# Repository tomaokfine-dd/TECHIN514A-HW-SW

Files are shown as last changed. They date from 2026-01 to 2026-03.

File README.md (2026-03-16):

# Screen Usage Load Meter

## 1. Project Overview

### What it does

Screen Usage Load Meter is a two-device system that estimates a user's screen usage load based on ambient light and user presence detection.  
A sensing device placed near a screen detects usage patterns, while a desktop display device visualizes the accumulated load using an analog gauge with a stepper motor and LED indicator.

### General Physical Sketch

The system consists of a small sensing module mounted near a computer screen and a desktop gauge display with a needle and LED.

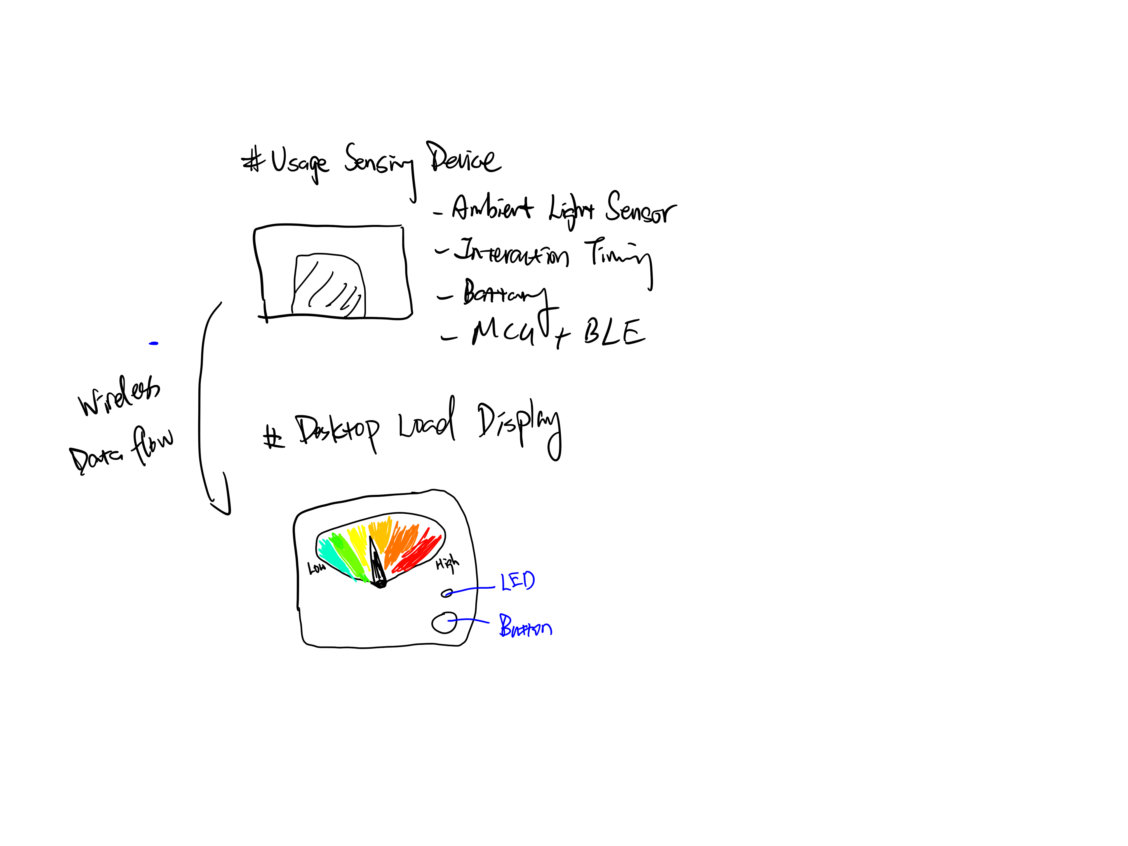
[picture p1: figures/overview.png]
Overview


---

## 2. Sensor Device

The sensor device is a compact, battery-powered module placed near a computer screen.  
It passively detects screen usage behavior without accessing the operating system and wirelessly transmits processed data to the display device via ESP-NOW.

### Sensors and Part Numbers

- **Ambient Light Sensor:** VEML7700 (Adafruit breakout)  
  Used to detect screen-on activity based on lux threshold (< 30 lux = screen off).
- **Time-of-Flight Distance Sensor:** VL53L4CX (Adafruit breakout)  
  Used to detect user presence in front of the screen (> 800mm = no person).

### Processor and Wireless

- **MCU + Wireless:** Seeed Studio XIAO ESP32C3 (ESP32-C3, ESP-NOW over Wi-Fi)

### Power

- 3.7V LiPo battery (1000 mAh)
- Onboard charging via XIAO ESP32C3 built-in battery management

### Sensor Device Sketch

The sensing module is mounted near the display, with the light sensor facing the screen and the distance sensor facing the user.  
The device operates autonomously and does not include user-facing controls.

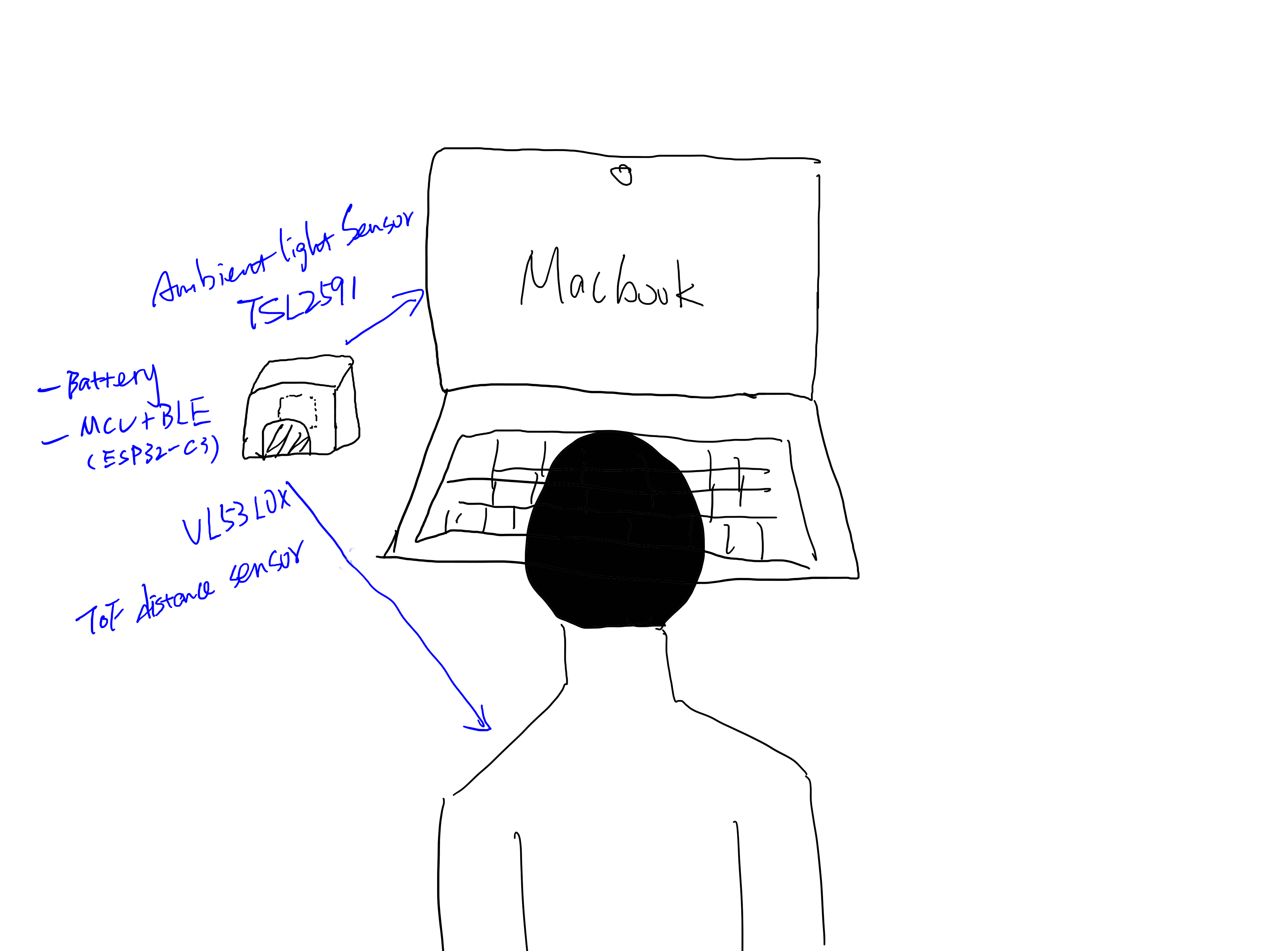
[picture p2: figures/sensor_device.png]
Sensor Device


---

## 3. Display Device

The display device is a desktop physical gauge that visualizes the current screen usage load.  
It integrates a stepper-motor-driven needle and an LED indicator, connected via breadboard prototype.

### Interface Components

- **Stepper Motor:** X27.168 bipolar gauge motor  
  Drives the gauge needle (2° per minute, full range 360°, returns to origin at 180 minutes).
- **LED:** NeoPixel WS2812B (single RGB LED for status indication)  
  Green (0–60 min) → Yellow (60–120 min) → Orange (120–180 min) → Bright Red (180+ min)

### Processor and Wireless

- **MCU + Wireless:** Seeed Studio XIAO ESP32C3  
  Receives data from the sensor device via ESP-NOW and controls motor and LED output.

### Power

- USB 5V (runs alongside computer)

### Display Device Sketch

The display features a gauge with a needle indicating cumulative usage load.  
An LED provides color-coded status, changing color every hour to indicate increasing usage intensity.

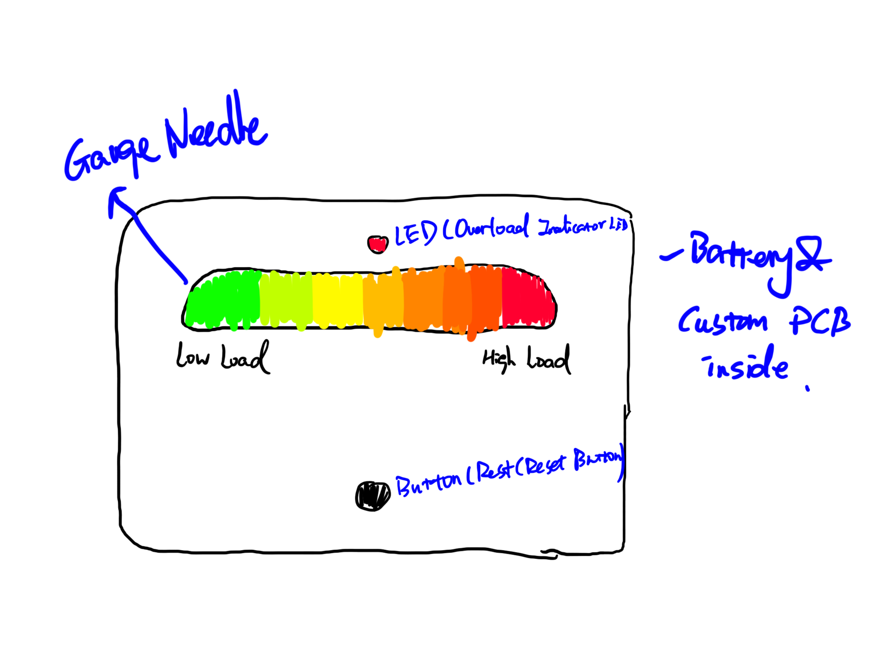
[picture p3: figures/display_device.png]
Display Device


---

## 4. Communication and System Diagram

The sensor device continuously transmits processed usage data to the display device using **ESP-NOW** (peer-to-peer Wi-Fi protocol, no router required). The system converts raw sensor signals into a cumulative screen usage time that controls the gauge needle position and LED color state.

**Data Flow:**

1. Sensor signals (ambient light lux + distance mm)
2. Threshold logic (lux < 30 = screen off; distance > 800mm = no person)
3. Usage timer accumulation (seconds counted when both conditions met)
4. ESP-NOW transmission (minutes sent every second to display device)
5. Output mapping to needle position (2°/min) and LED color stage

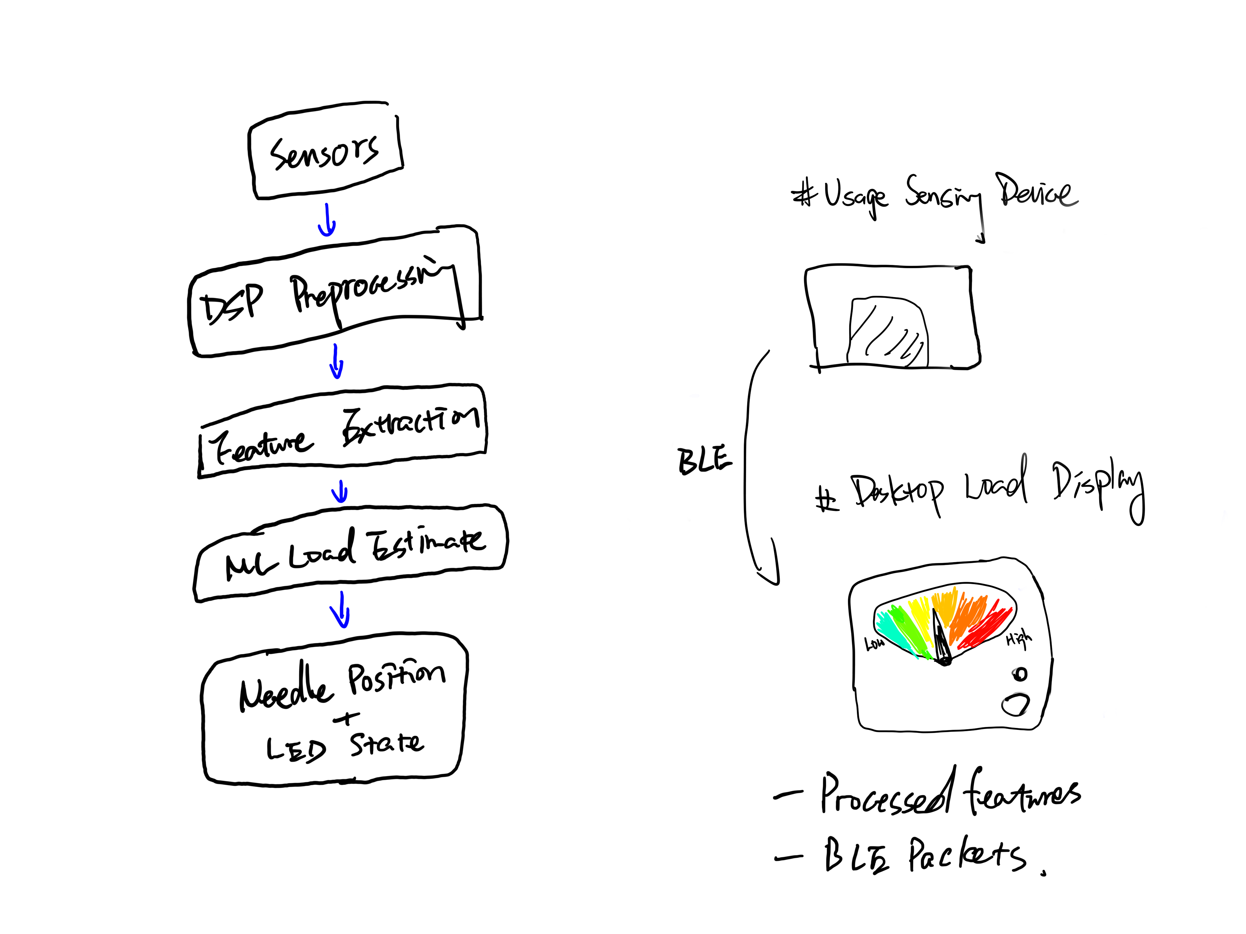
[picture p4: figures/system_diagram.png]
System Diagram


---

## 5. DSP and Signal Processing Approach

- **DSP:**  
  Dual-threshold detection logic combines ambient light and distance signals. Screen-off state is detected when lux drops below 30. User absence is detected when ToF distance exceeds 800mm. Usage time accumulates only when both sensors confirm active use simultaneously.
- **Note:**  
  No ML model is used in the current implementation. Detection is rule-based with fixed thresholds calibrated to typical indoor desktop environments. False positive rate is approximately 5%, primarily caused by ambient light changes such as overhead lighting.

---

## 6. Datasheets

All component datasheets are included in the `/datasheets` folder, including:

- ESP32-C3 (Seeed Studio XIAO ESP32C3)
- VEML7700 Ambient Light Sensor (Vishay / Adafruit breakout)
- VL53L4CX Time-of-Flight Distance Sensor (ST / Adafruit breakout)
- X27.168 Bipolar Gauge Stepper Motor (Switec/Juken)
- WS2812B RGB LED (NeoPixel)
- Custom Sensor Board PCB (KiCad design files)

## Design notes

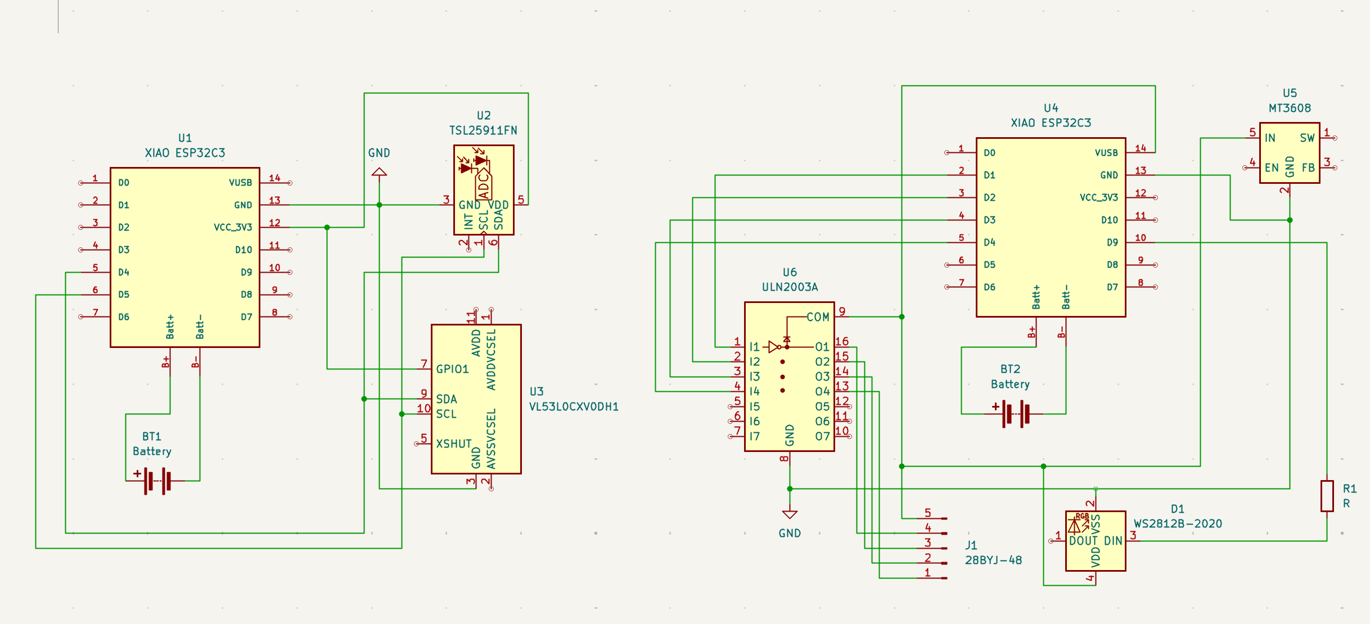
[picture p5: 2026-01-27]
kicad/Untitled/electrical schematics.png

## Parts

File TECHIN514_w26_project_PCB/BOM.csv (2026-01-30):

Reference | Qty | Value | DNP | Exclude from BOM | Exclude from Board | Footprint | Datasheet
C1,C2,C3,C4 | 4 | 1μF |  |  |  | Capacitor_SMD:C_0603_1608Metric_Pad1.08x0.95mm_HandSolder | ~
C5 | 1 | 10μF |  |  |  | Capacitor_SMD:C_0603_1608Metric_Pad1.08x0.95mm_HandSolder | ~
C6 | 1 | ≥10µF |  |  |  | Capacitor_SMD:C_0603_1608Metric_Pad1.08x0.95mm_HandSolder | ~
D1 | 1 | LED |  |  |  | LED_SMD:LED_0603_1608Metric_Pad1.05x0.95mm_HandSolder | ~
J1 | 1 | Conn_01x04 |  |  |  | Connector_PinSocket_1.00mm:PinSocket_1x04_P1.00mm_Vertical | ~
R1,R2,R4 | 3 | 4.7k |  |  |  | Resistor_SMD:R_0603_1608Metric_Pad0.98x0.95mm_HandSolder | ~
R3 | 1 | 330 |  |  |  | Resistor_SMD:R_0603_1608Metric_Pad0.98x0.95mm_HandSolder | ~
U2 | 1 | APDS-9960 |  |  |  | Sensor:Avago_APDS-9960 | https://docs.broadcom.com/doc/AV02-4191EN
U3 | 1 | MIC5376-2.8YC5-TR |  |  |  | APDS-9960:SC-70_C5_MCH | MIC5376-2.8YC5-TR

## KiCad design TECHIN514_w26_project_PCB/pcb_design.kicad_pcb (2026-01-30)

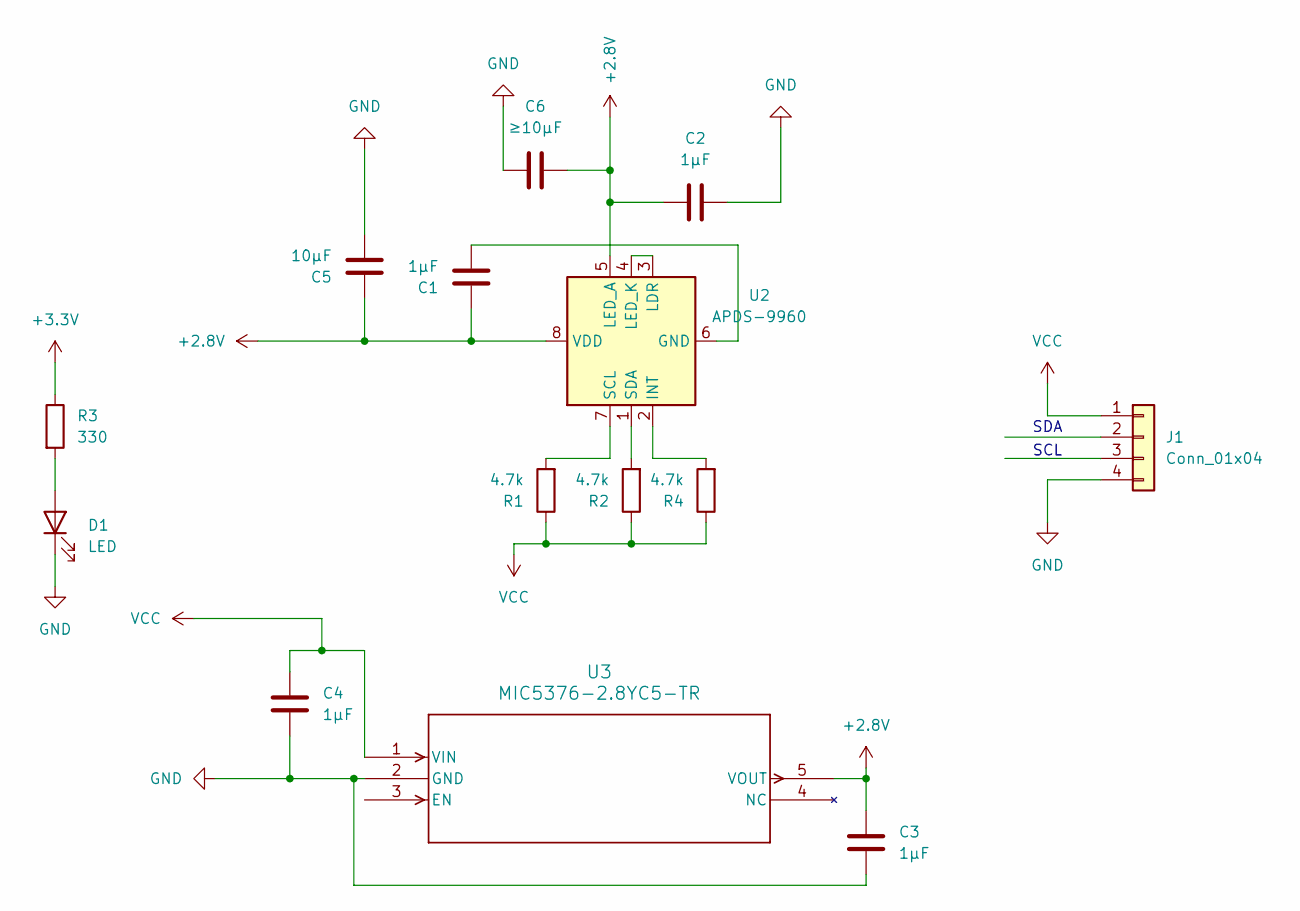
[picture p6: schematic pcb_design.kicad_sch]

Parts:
C1, C2, C3, C4: 1μF; C_0603_1608Metric_Pad1.08x0.95mm_HandSolder
C5: 10μF; C_0603_1608Metric_Pad1.08x0.95mm_HandSolder
C6: ≥10µF; C_0603_1608Metric_Pad1.08x0.95mm_HandSolder
D1: LED; LED_0603_1608Metric_Pad1.05x0.95mm_HandSolder
J1: Conn_01x04; PinSocket_1x04_P1.00mm_Vertical
R1, R2, R4: 4.7k; R_0603_1608Metric_Pad0.98x0.95mm_HandSolder
R3: 330; R_0603_1608Metric_Pad0.98x0.95mm_HandSolder
U2: APDS-9960; Avago_APDS-9960
U3: MIC5376-2.8YC5-TR; SC-70_C5_MCH

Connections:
+2.8V: C1.1, C2.1, C3.1, C5.1, C6.1, U2.5 (LED_A), U2.8 (VDD), U3.5 (VOUT)
+3.3V: R3.1
GND: C2.2, C3.2, C4.2, C5.2, C6.2, D1.1 (K), J1.4, U3.2 (GND)
unnamed: D1.2 (A), R3.2
unnamed: C1.2, U2.6 (GND)
unnamed: R4.2, U2.2 (INT)
unnamed: U2.3 (LDR), U2.4 (LED_K)
unnamed: R1.2, U2.7 (SCL)
unnamed: R2.2, U2.1 (SDA)
VCC: C4.1, J1.1, R1.1, R2.1, R4.1, U3.1 (VIN)

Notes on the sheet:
SDA
SCL

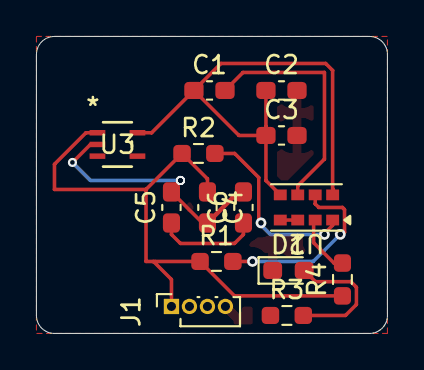
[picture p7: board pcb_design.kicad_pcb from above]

Board: 2 copper layers, 19.5 x 16.5 mm, 14 parts (0 on the bottom side), 9 nets.

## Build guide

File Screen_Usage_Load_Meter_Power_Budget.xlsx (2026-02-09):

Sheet: System Parameters
System Parameters (defined by hardware) |  |  |  | Profiles (usage of each component mode - defined by software and usage)
 | form the datasheets
 |  |  |  | "off" | "sensing" | "interactive"
Processor | 120 |  | 0 | 0.05 | 0.1
Active | 60 | mW | 0 | 20% | 30% | 0%
Idle | 0.28 | mW | 1 | 75% | 60% | 0%
Sleep | 1.00035 | mW |  | 0% | 0% | 0%
LED | 6.6 |  | 0 | 0.03 | 0.05
On | 5.0004 | mW |  | 0% | 0% | 0%
Sensor | 57 |  | 0 | 0.05 | 0.1
On | 0.03 | mW | 0 | 95% | 90% | 0%
Idle | 0.001 | mW | 1 | 0% | 0% | 0%
Off | 1.00045 | mW |  | 0% | 0% | 0%
Display | 0 |  | 0 | 0 | 0
On | 0 | mW | 0 | 0% | 0% | 0%
Off (leakage) | 1.0006 | mW |  | 0% | 0% | 0%
Radio | 0
Data Rate | 350 | bps | 0 | 100% | 90% | 0% |  | Total power in profile (mw) |  |  | Maximum Time
Standby Power | 1200 | mW | 0 | 0% | 10% | 0% |  | "off" | 365.2865 | mW | 0.008523583543 | hours
TX Power | 0 | mW | 1 | 0% | 0% | 0% |  | "sensing" | 459.225 | mW | 0.006780009799 | hours
RX Power | 10.000001 | mW |  | 0% | 0% | 0% |  | "interactive" | 0 | mW | #DIV/0! | hours
 |  |  | 16 | 7 | 1
 |  |  |  | 16 | 7 | 1 | hours/day typical usage | Effective Battery Capacity
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

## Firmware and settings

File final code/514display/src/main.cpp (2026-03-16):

#include <Arduino.h>
#include <WiFi.h>
#include <esp_now.h>
#include <Adafruit_NeoPixel.h>

#define PIN1 4
#define PIN2 6
#define PIN3 8
#define PIN4 9
#define LED_PIN 3
#define NUM_LEDS 1

Adafruit_NeoPixel strip(NUM_LEDS, LED_PIN, NEO_GRB + NEO_KHZ800);

unsigned long receivedMinutes = 0;
unsigned long lastMinutes = 0;
int motorPos = 0;
int lastStage = -1;

typedef struct { unsigned long minutes; } DataPacket;

int motorSteps[4][4] = {
  {1,0,0,1},{1,0,1,0},{0,1,1,0},{0,1,0,1}
};

void setMotor(int step) {
  digitalWrite(PIN1, motorSteps[step][0]);
  digitalWrite(PIN2, motorSteps[step][1]);
  digitalWrite(PIN3, motorSteps[step][2]);
  digitalWrite(PIN4, motorSteps[step][3]);
}

void moveMotor(int steps) {
  if (steps > 0) {
    for (int i = 0; i < steps; i++) {
      motorPos++;
      setMotor(motorPos % 4);
      delay(2);
    }
  } else {
    for (int i = 0; i < abs(steps); i++) {
      motorPos--;
      setMotor(((motorPos % 4) + 4) % 4);
      delay(2);
    }
  }
}

void onReceive(const uint8_t* mac, const uint8_t* data, int len) {
  DataPacket packet;
  memcpy(&packet, data, sizeof(packet));
  receivedMinutes = packet.minutes;
}

int getStage(unsigned long min) {
  if (min < 60) return 0;
  if (min < 120) return 1;
  if (min < 180) return 2;
  return 3;
}

void setLED(int stage) {
  if (stage == 0) {
    strip.setBrightness(20);
    strip.setPixelColor(0, strip.Color(0, 255, 0));
  } else if (stage == 1) {
    strip.setBrightness(20);
    strip.setPixelColor(0, strip.Color(255, 200, 0));
  } else if (stage == 2) {
    strip.setBrightness(20);
    strip.setPixelColor(0, strip.Color(255, 80, 0));
  } else {
    strip.setBrightness(150);
    strip.setPixelColor(0, strip.Color(255, 0, 0));
  }
  strip.show();
}

void setup() {
  Serial.begin(115200);

  pinMode(PIN1, OUTPUT);
  pinMode(PIN2, OUTPUT);
  pinMode(PIN3, OUTPUT);
  pinMode(PIN4, OUTPUT);

  WiFi.mode(WIFI_STA);
  esp_now_init();
  esp_now_register_recv_cb(onReceive);

  strip.begin();
  delay(500);
  setLED(0);

  Serial.println("Started");
}

void loop() {
  if (receivedMinutes != lastMinutes) {
    int diff = (int)(receivedMinutes - lastMinutes);

    if (receivedMinutes >= 180) {
      
      moveMotor(-motorPos);
      Serial.println("Returned to origin");
    } else {
      
      moveMotor(diff * 6);
    }
    lastMinutes = receivedMinutes;
  }

  int stage = getStage(receivedMinutes);
  if (stage != lastStage) {
    setLED(stage);
    lastStage = stage;
  }

  Serial.printf("Total: %lu min | Motor pos: %d\n", receivedMinutes, motorPos);
  delay(1000);
}

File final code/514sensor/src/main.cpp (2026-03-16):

#include <Arduino.h>
#include <Wire.h>
#include <WiFi.h>
#include <esp_now.h>
#include <Adafruit_VEML7700.h>
#include <vl53l4cx_class.h>

Adafruit_VEML7700 veml;
VL53L4CX sensor(&Wire, 2);

#define DIST_THRESHOLD 800
#define LUX_MIN 30.0

// Display Board MAC address
uint8_t displayMac[] = {0x98, 0x3D, 0xAE, 0xAC, 0xF7, 0x70};

unsigned long screenOnSeconds = 0;
unsigned long lastCheckTime = 0;

typedef struct {
  unsigned long minutes;
} DataPacket;

void onSent(const uint8_t* mac, esp_now_send_status_t status) {
  Serial.printf("Send %s\n", status == ESP_NOW_SEND_SUCCESS ? "success" : "failed");
}

void setup() {
  Serial.begin(115200);
  Wire.begin();
  delay(1000);

  veml.begin();

  // Initialize VL53L4CX
  pinMode(2, OUTPUT);
  digitalWrite(2, LOW);
  delay(10);
  digitalWrite(2, HIGH);
  delay(10);
  sensor.begin();
  sensor.VL53L4CX_Off();
  sensor.InitSensor(0x52);
  sensor.VL53L4CX_StartMeasurement();

  // Initialize ESP-NOW
  WiFi.mode(WIFI_STA);
  esp_now_init();
  esp_now_register_send_cb(onSent);

  esp_now_peer_info_t peerInfo = {};
  memcpy(peerInfo.peer_addr, displayMac, 6);
  peerInfo.channel = 0;
  peerInfo.encrypt = false;
  esp_now_add_peer(&peerInfo);

  Serial.println("ESP-NOW sender started");
  lastCheckTime = millis();
}

void loop() {
  // Read light level
  float lux = veml.readLux();
  bool screenOn = lux >= LUX_MIN;

  // Read distance
  int dist = -1;
  VL53L4CX_MultiRangingData_t data;
  uint8_t ready = 0;
  sensor.VL53L4CX_GetMeasurementDataReady(&ready);
  if (ready) {
    sensor.VL53L4CX_GetMultiRangingData(&data);
    if (data.NumberOfObjectsFound > 0) {
      int d = data.RangeData[0].RangeMilliMeter;
      int s = data.RangeData[0].RangeStatus;
      if (s == 0 && d > 0 && d < 6000) dist = d;
    }
    sensor.VL53L4CX_ClearInterruptAndStartMeasurement();
  }

  // Determine if user is at computer
  bool personHere = dist > 0 && dist < DIST_THRESHOLD;
  bool usingComputer = screenOn && personHere;

  // Update timer and send data every second
  if (millis() - lastCheckTime >= 1000) {
    if (usingComputer) screenOnSeconds++;
    lastCheckTime = millis();

    DataPacket packet;
    packet.minutes = screenOnSeconds / 60;
    esp_now_send(displayMac, (uint8_t*)&packet, sizeof(packet));
    Serial.printf("Sent: %lu min\n", packet.minutes);
  }

  Serial.printf("Lux:%.1f | Dist:%dmm | Status:%s\n",
    lux, dist, usingComputer ? "In use" : "Not in use");

  delay(100);
}

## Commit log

2026-01-20 Update GentiamElectronics-28BYJ-48-Stepper-Motor-Datasheet-Rev20220925-final
2026-01-26 Create KiCad
2026-01-27 Add placeholder comments to KiCad file
2026-03-16 Revise README for clarity and detail enhancements
    Updated project description, sensor details, and communication method. Enhanced clarity on system components and functionality.
